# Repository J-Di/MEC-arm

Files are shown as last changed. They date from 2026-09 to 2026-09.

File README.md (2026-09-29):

<h1>MEC-Arm</h1>

MEC-Arm logo

## Overview
MEC-Arm is a six degree of freedom robotic arm which is currently being designed from scratch by 2 students team. The team is composed of a mechanical and electrical engineering student, working together to realize this shared personal project. The overall objective is to create a fully functional, precise, and practical arm, while creating many of the required components from scratch along the way. This repository contains both the mechanical and the electrical side of the project, after all, this is a **M**echanical **E**lectrical **C**ollaboration -Arm :)

Find all the Documentation here: [MEC-Arm Documentation Page](https://j-di.github.io/MEC-arm/)

### Key Features:

#### Arm
- Joint layout: waist (roll), shoulder (pitch), elbow (pitch), 3-axis wrist (roll, pitch, roll)
- Arm weight: TBD
- End effector: gripper, driven by the 7th motor
- Max joint speed: 90 RPM (shoulder)

#### Actuation

- Actuators: 7× brushless motors with custom cycloidal gearboxes
- Gear ratios: 19:1, 25:1, 15:1
- Motor control: FOC at every joint
- Position feedback: on-board magnetic encoders

#### Power & control

- Battery: 6S LiPo, 25.2–18V, TBD mA
- Communication: CAN bus 
- Host: controlled from a raspberry pi

## Timeline

```mermaid
flowchart LR
    subgraph Shared
        A[Requirements defined]
        B[Arm structure decided]
        C[Joint torque calculations]
        D[Motors sourced]
    end

    subgraph Electrical
        E[ESC design]
        H[ESC bring-up and testing]
        P[Power distribution and coordination board]
    end

    subgraph Mechanical
        F[Preliminary arm structure]
        G[Gearbox design]
        I[Joint assembly]
    end

    K[Per-joint gearbox testing]
    L[Torque characterization]
    J[Full arm integration]
    S[Software begins]

    A --> B --> C --> D
    D --> E --> H
    D --> P
    D --> F --> G --> I
    H --> K
    G --> K
    K --> L
    L --> J
    I --> J
    P --> J
    J --> S

    classDef done fill:#2da44e,stroke:#1a7f37,color:#fff
    classDef wip  fill:#d4a72c,stroke:#9a6700,color:#fff
    classDef todo fill:#8c959f,stroke:#57606a,color:#fff
    class A,B,C,D,F done
    class E,G,P wip
    class H,I,J,K,L,S todo
```

🟩 Done · 🟨 In progress · ⬜ Planned

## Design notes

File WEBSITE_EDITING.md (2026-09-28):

# Editing the MEC-Arm website

The website is plain HTML, CSS, and JavaScript in the repository's `docs/` folder. GitHub Pages publishes that folder from `main`. There is no npm install, generator, or build command.

## Where things live

| File or folder | Edit it to change… |
| --- | --- |
| `docs/index.html` | The homepage text, project goals, image gallery, timeline lists, and documentation cards. |
| `docs/styles.css` | Colors, spacing, type, cards, sidebar, and mobile layout. Sitewide color variables are at the top. |
| `docs/electrical/` | Electrical landing page, hardware boards and subsystems, and firmware pages. |
| `docs/mechanical/` | Structure, gearbox, joint, and gripper pages. |
| `docs/software/` | Host, motion, and testing-tool pages. |
| `docs/docs.js` | Shared header, sidebar, breadcrumbs, and the list of project pages (`sitePages`). |
| `docs/gallery.js` | Previous, next, and slide selection for the homepage gallery. |
| `docs/assets/gallery-placeholder.svg` | Temporary image shown until you add project photos. |
| `docs/assets/MEC_Logo.svg` | The supplied logo used in the header, footer, homepage, and favicon. |

Each documentation topic is a real `.html` file. For example, the ESC sensing page is `docs/electrical/hardware/esc/feedback.html`. A folder's landing page is its `index.html`, such as `docs/electrical/hardware/esc/index.html`.

## Update existing text

Open the page's `.html` file in an editor. Its `<h1>` is the page title. Paragraphs and lists in `<main class="docs-content">` are the visible content. The current descriptions are starting points; replace them with your design notes, images, tables, and measured results as the project develops. Keep planned values distinct from measured results.

On the homepage, edit the introductory paragraphs, the three lists in `<section class="status-band">`, and the three cards in `<section class="documentation">`. To update a milestone, move its `<li>…</li>` to the appropriate list. The small status label on an individual topic page is inside `<span class="status-pill">…</span>`.

The homepage's GitHub link is directly in `docs/index.html`. The GitHub link on documentation pages is set by `repoUrl` near the bottom of `docs/docs.js`.

To add an image, place it in `docs/assets/` and use a relative path from the page. From `docs/index.html` that looks like `<img src="assets/photo.jpg" alt="A description">`. From `docs/electrical/index.html`, use `../assets/photo.jpg`.

### Replace homepage gallery images

The four `<figure class="gallery-slide">` blocks in `docs/index.html` are the arm, ESC board, gearbox, and assembly slides. Place your photos in `docs/assets/`, then change each slide's `<img src="assets/gallery-placeholder.svg">` to its photo path (for example, `src="assets/arm.jpg"`). Update the image's `alt` text and the `<figcaption>` as well. The placeholder is reused for now; it is not a drawing of the actual arm. The previous/next arrows and four dots work without any changes to `gallery.js`.

### Add the S-Curve algorithm diagram

The page is `docs/electrical/firmware/s-curve.html`. Keep your editable `.drawio` file in `docs/assets/trajectory/` and export a separate SVG into the same folder for the website. SVG keeps text and lines sharp when readers zoom into a large diagram. Replace the "Detailed draw.io diagram coming soon" block on that page with:

```html
<figure class="doc-figure">
  <a href="../../assets/trajectory/s-curve-algorithm.svg" target="_blank" rel="noopener noreferrer">
    <img src="../../assets/trajectory/s-curve-algorithm.svg" alt="Diagram of the S-Curve trajectory planner" loading="lazy">
  </a>
  <figcaption><a href="../../assets/trajectory/s-curve-algorithm.svg" target="_blank" rel="noopener noreferrer">Open the full-size algorithm diagram ↗</a></figcaption>
</figure>
```

The inline preview gives context while the full-size link lets readers zoom and pan through the details. If the exported SVG is very large, a PNG preview with the SVG as the full-size link also works.

## Add a new topic page

Example: add a PWM page under the ESC.

1. Copy `docs/electrical/hardware/esc/feedback.html` to `docs/electrical/hardware/esc/pwm.html`.
2. Edit its `<title>`, `<h1>`, description, status, and main content. Give its `<body>` a unique `data-page="esc-pwm"`. Keep `data-root="../../../"` because it is three folders below `docs/`.
3. Add this entry to the `sitePages` array in `docs/docs.js` next to the other ESC pages:

   ```js
   { id: "esc-pwm", label: "PWM", path: "electrical/hardware/esc/pwm.html", parent: "esc" },
   ```

4. Add a card linking to it in `docs/electrical/hardware/esc/index.html`, following one of the existing `<a class="topic-card">` examples.

The sidebar and breadcrumbs are built from `sitePages`. Use a unique `id`, make `parent` the ID of its containing topic, and make `path` relative to `docs/`. For a page at another depth, `data-root` needs one `../` for each folder between the page and `docs/`.

## Preview and publish

You can open `docs/index.html` in a browser for a quick local preview. All page links are relative.

After editing, run from the repository root:

```bash
git add docs WEBSITE_EDITING.md
git commit -m "Update project website"
git push
```

Check **Settings → Pages** if the site does not update. It should publish from `main` and `/docs`. Browser caches may take a few minutes to refresh; `Ctrl+Shift+R` reloads the current version.

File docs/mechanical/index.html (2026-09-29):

Skip to content

MEC-ARM / PROJECT DOCUMENTATION

Design in progress

# Mechanical

The six axis structure, seven actuators, and custom gearboxes turn the electrical system into a practical arm.

## Explore this area

↗Arm structureSix axis layout and CAD↗Cycloidal gearboxesCustom reductions and testing↗Joint assembliesPer-joint integration↗GripperMotor-driven end effector

## Layout

The joint sequence is waist roll, shoulder pitch, elbow pitch, and a roll–pitch–roll wrist. A seventh motor is planned for the gripper.

## Design and verification

The preliminary structure and joint torque calculations are listed as complete. Gearbox design is in progress; joint assembly and torque characterization are future milestones.

This project is ongoing. Design goals, planned work, and measured results will be distinguished as the pages grow.

## Continue exploring

← Project overview

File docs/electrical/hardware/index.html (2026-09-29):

Skip to content

MEC-ARM / PROJECT DOCUMENTATION

Design in progress

# Electrical hardware

Two board families form the planned electrical backbone: one controller behind each motor and one central power and coordination board.

## Explore this area

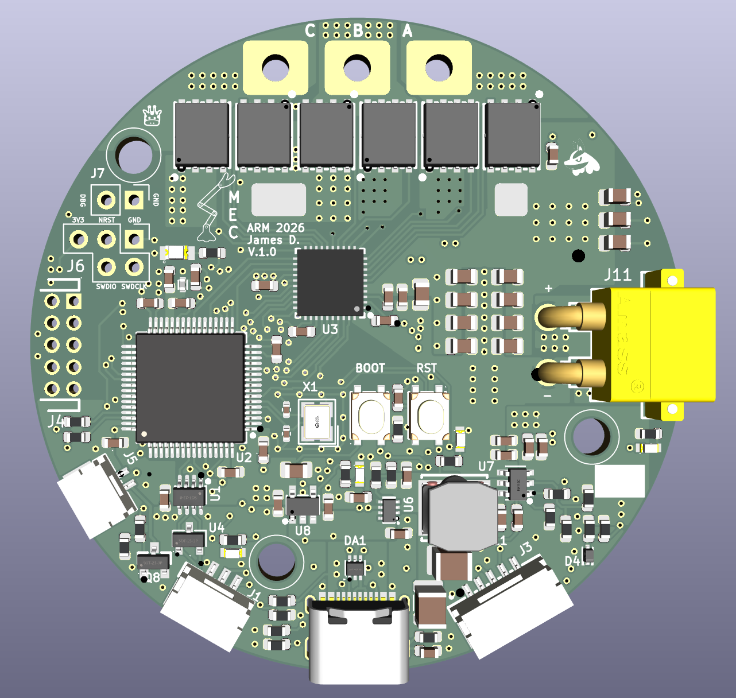
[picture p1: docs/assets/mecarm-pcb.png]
Joint ESC PCB
↗ Joint ESC  Compact controller at each motor ↗Power & coordination boardNot designed yetCentral power and connections

## Joint-level electronics

Each ESC is intended to fit behind a motor so it can read the motor-shaft magnetic encoder without a separate external encoder coupling. The same controller design is intended to serve different joints.

## Central electronics

The separate board is planned to distribute and convert power, coordinate connections, and provide a host-to-arm interface. Its final architecture remains under design.

This project is ongoing. Design goals, planned work, and measured results will be distinguished as the pages grow.

## Continue exploring

← ElectricalProject overview ↗

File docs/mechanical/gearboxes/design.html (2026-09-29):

Skip to content

MEC-ARM / PROJECT DOCUMENTATION

Design in progress

# Gearbox design

A dedicated record for cycloidal geometry, packaging, materials, and mechanical choices.

## Known direction

Custom cycloidal gearboxes are planned, with ratio targets of 19:1, 25:1, and 15:1. Final joint assignment and detailed geometry are still open.

## Design details to add

Record profiles, pin and bearing sizes, reduction calculations, tolerances, CAD revisions, and design tradeoffs here.

This project is ongoing. Design goals, planned work, and measured results will be distinguished as the pages grow.

## Continue exploring

← Cycloidal gearboxesProject overview ↗

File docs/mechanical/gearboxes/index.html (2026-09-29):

Skip to content

MEC-ARM / PROJECT DOCUMENTATION

Design in progress

# Cycloidal gearboxes

Custom gearboxes are planned for the brushless actuators to match motor speed to joint torque and motion.

## Explore this area

↗Gearbox designProfiles and packaging↗Gearbox testingTorque and backlash validation

## Current targets

The README lists ratio targets of 19:1, 25:1, and 15:1. Assignment of each ratio to a specific joint is not stated there, so this site does not assign them.

## Testing plan

Document the gearbox geometry, bearing and pin choices, tolerances, assembly, efficiency, backlash, and per-joint torque tests as they become available.

This project is ongoing. Design goals, planned work, and measured results will be distinguished as the pages grow.

## Continue exploring

← MechanicalProject overview ↗

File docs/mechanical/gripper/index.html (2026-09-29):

Skip to content

MEC-ARM / PROJECT DOCUMENTATION

Planned

# Gripper

The end effector is planned as a gripper driven by the seventh brushless motor.

## Current concept

The README identifies a motor-driven gripper but does not define finger geometry, transmission, force, or stroke yet.

## Future content

Add mechanism options, grasp targets, force estimates, CAD, and tests when the end-effector design begins.

This project is ongoing. Design goals, planned work, and measured results will be distinguished as the pages grow.

## Continue exploring

← MechanicalProject overview ↗

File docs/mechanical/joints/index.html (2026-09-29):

Skip to content

MEC-ARM / PROJECT DOCUMENTATION

Planned

# Joint assemblies

Each joint brings together a motor, gearbox, support structure, encoder, and compact ESC.

## Explore this area

↗Waist jointBase roll axis↗Shoulder & elbowLoad-bearing pitch axes↗Three-axis wristRoll–pitch–roll orientation

## Integration

The joint assembly milestone follows the preliminary arm structure and gearbox design. Per-joint gearbox testing and torque characterization are planned before full integration.

## Per-joint records

The pages below separate the waist, shoulder and elbow, and wrist. Each can grow to include ratio, limits, mass, CAD, and measured performance.

This project is ongoing. Design goals, planned work, and measured results will be distinguished as the pages grow.

## Continue exploring

← MechanicalProject overview ↗

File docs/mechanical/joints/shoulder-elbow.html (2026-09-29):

Skip to content

MEC-ARM / PROJECT DOCUMENTATION

Planned

# Shoulder & elbow

The two pitch axes position the arm and carry much of its working load.

## Role

Shoulder pitch and elbow pitch follow the waist roll axis. The README lists a 90 RPM maximum joint-speed target for the shoulder.

## To document

Add each joint's torque requirement, gearbox, structural support, range, CAD, and tests as the assemblies mature.

This project is ongoing. Design goals, planned work, and measured results will be distinguished as the pages grow.

## Continue exploring

← Joint assembliesProject overview ↗

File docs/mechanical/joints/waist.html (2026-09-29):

Skip to content

MEC-ARM / PROJECT DOCUMENTATION

Planned

# Waist joint

The base roll axis supports and rotates the rest of the arm.

## Role

The waist is the first rotational axis in the six degree of freedom layout.

## To document

Add bearing support, gearbox ratio, motor selection, range, wiring path, CAD, and load cases when the joint design is ready.

This project is ongoing. Design goals, planned work, and measured results will be distinguished as the pages grow.

## Continue exploring

← Joint assembliesProject overview ↗

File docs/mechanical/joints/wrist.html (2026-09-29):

Skip to content

MEC-ARM / PROJECT DOCUMENTATION

Planned

# Three-axis wrist

The roll–pitch–roll wrist orients the end effector at the end of the arm.

## Layout

Three rotational axes at the wrist complete the six degree of freedom joint sequence.

## To document

Add packaging, motor and gearbox choices, axis intersections, encoder access, cable routing, and validation once defined.

This project is ongoing. Design goals, planned work, and measured results will be distinguished as the pages grow.

## Continue exploring

← Joint assembliesProject overview ↗

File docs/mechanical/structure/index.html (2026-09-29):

Skip to content

MEC-ARM / PROJECT DOCUMENTATION

Preliminary design completed

# Arm structure

The arm layout organizes six degrees of freedom from the waist through the wrist.

## Joint sequence

Waist roll → shoulder pitch → elbow pitch → wrist roll → wrist pitch → wrist roll. The current plan adds a separate motor-driven gripper.

## Next documentation

Add CAD renders, dimensions, mass estimates, materials, joint range limits, and assembly drawings as the design is finalized. The arm's final weight is still TBD.

This project is ongoing. Design goals, planned work, and measured results will be distinguished as the pages grow.

## Continue exploring

← MechanicalProject overview ↗

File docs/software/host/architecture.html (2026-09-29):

Skip to content

MEC-ARM / PROJECT DOCUMENTATION

Planned

# Host architecture

The host's processes, interfaces, and command flow will be documented here.

## Current boundary

The Raspberry Pi is the planned host, while motor control is assigned to the distributed joint ESCs.

## To define

Add process boundaries, configuration, state handling, network transport, startup order, and telemetry storage after the software architecture is chosen.

This project is ongoing. Design goals, planned work, and measured results will be distinguished as the pages grow.

## Continue exploring

← Raspberry Pi hostProject overview ↗

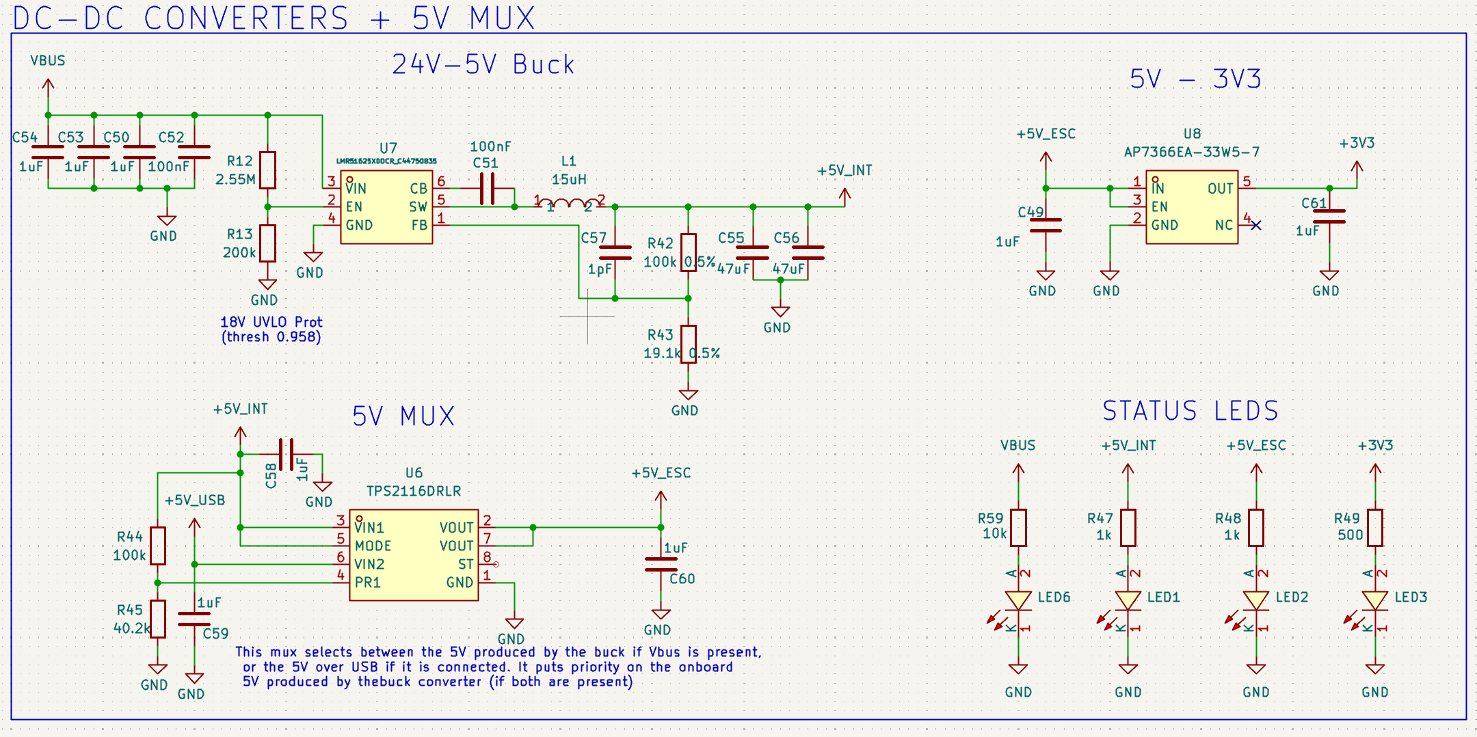
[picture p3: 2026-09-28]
docs/assets/esc/mec-converters-sch.png

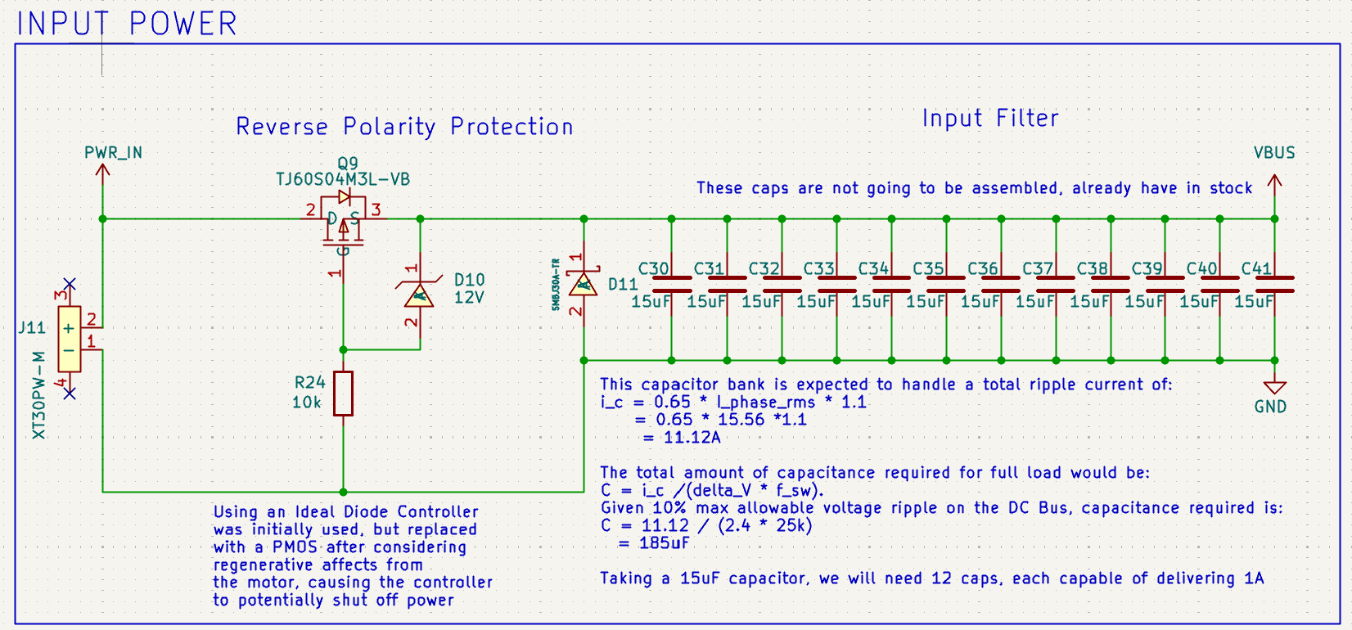
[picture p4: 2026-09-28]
docs/assets/esc/mec-pwr-filters-sch.png

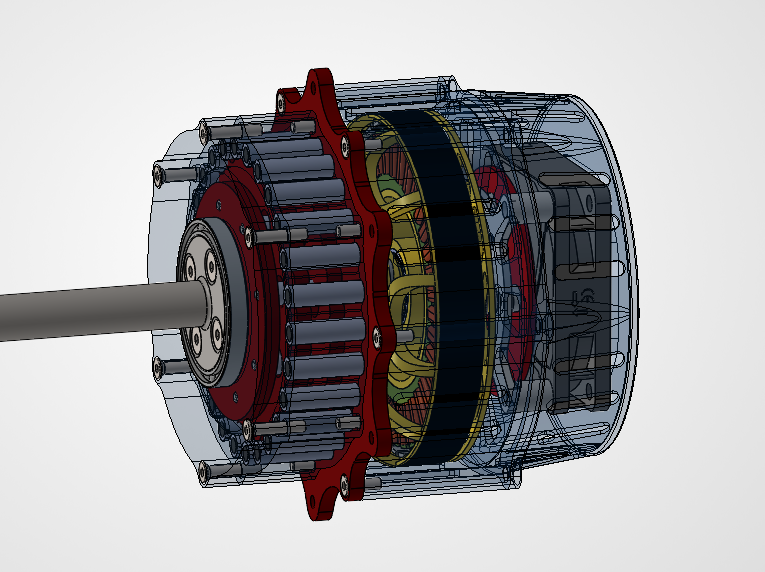
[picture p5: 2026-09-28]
docs/assets/mecarm-gearbox-prelim.png

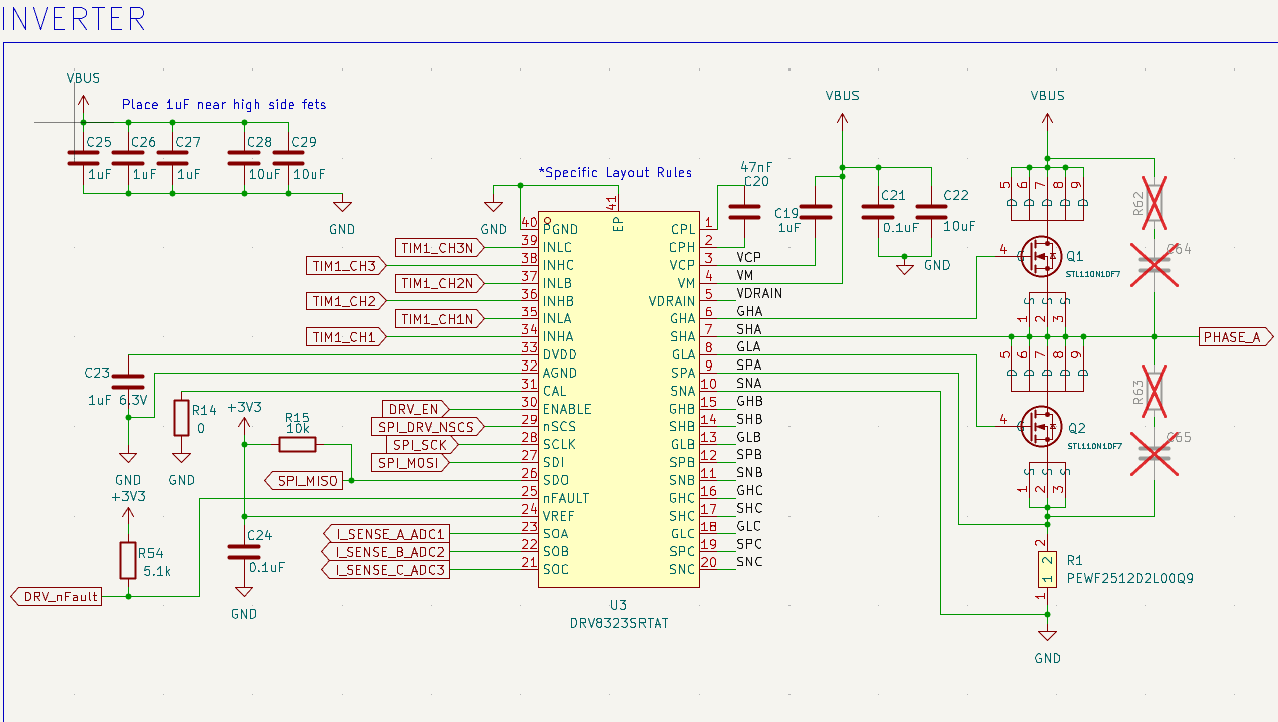
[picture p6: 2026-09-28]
docs/assets/esc/mec-inverter-sch.png

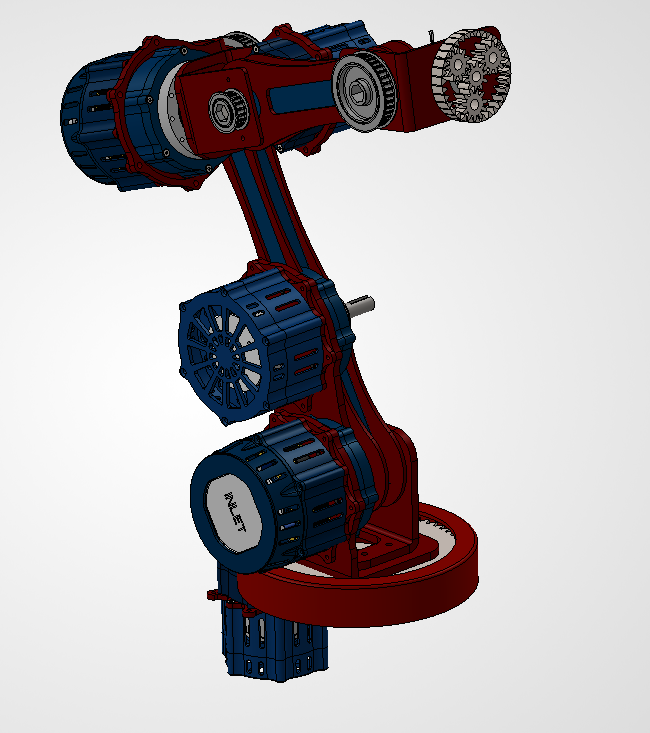
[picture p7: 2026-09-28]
docs/assets/mecarm-prelim.png

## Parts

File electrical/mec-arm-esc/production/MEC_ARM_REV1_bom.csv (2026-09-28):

Designator | Footprint | Quantity | Value | LCSC Part #
C10, C11, C16, C44, C45, C7, C8, C9 | C_0603 | 8 | 100nf | C108079
C12 | C_0805 | 1 | 10uf | C711098
C13, C43 | C_0603 | 2 | 10nf | C519406
C14, C15, C49, C58, C59, C60, C61 | C_0603 | 7 | 1uf | C106248
C17, C18 | 0402 | 2 | 16pF | C5142569
C19 | C_0603 | 1 | 1uF | C14664
C20 | C_0603 | 1 | 47nF | C513577
C21 | C_0603 | 1 | 0.1uF | C14663
C22, C28, C29 | C_0805 | 3 | 10uF | C162422
C23 | C_0603 | 1 | 1uF 6.3V | C2169508
C24, C42, C62 | C_0603 | 3 | 0.1uF | C108079
C25, C26, C27, C50, C53, C54 | C_0603 | 6 | 1uF | C559769
C30, C31, C32, C33, C34, C35, C36, C37, C38, C39, C40, C41 | C_0805 | 12 | 15uF | C162422
C46, C47, C48 | C_0603 | 3 | 10pF | C2168592
C51, C52 | C_0603 | 2 | 100nF | C14663
C55, C56 | 1210 | 2 | 47uF | C77101
C57 | C_0603 | 1 | 1pF | C29936
D1, D2, D3, D4, D5 | SOD-523_L1.2-W0.8-LS1.6-RD-1 | 5 | BAT30KFILM | C2926449
D10 | SOD-123F_L2.8-W1.8-LS3.7-RD | 1 | 12V | C177013
D11 | SMB_L4.6-W3.6-LS5.3-RD | 1 | SMBJ30A-TR | C133663
DA1, DA2 | SOT-666-6_L1.6-W1.2-P0.50-LS1.6-BR | 2 | USBLC6-2P6 | C15999
FB1 | L0402 | 1 | BLM15BX601SN1D | C710336
J1 | CONN-SMD_GT-A1257WRS-103SBT01 | 1 | GT-A1257WRS-103SBT01 | C22472755
J10 | PHASE_PAD | 1 | ~
J11 | CONN-TH_XT30PW-M | 1 | XT30PW-M | C431092
J12 | 3x3BusBar Pad | 1 | ~
J3 | CONN-SMD_5P-P1.25_SM05B-GHS-TB-LF-SN | 1 | SM05B-GHS-TB | C189896
J5 | CONN-SMD_SM02B-GHS-TB-LF-SN | 1 | XY-SM02B-GHS-TB | C54582897
J8 | TestPadArray1x4 | 1 | ~
J9 | 5x3BusBar Pad | 1 | ~
L1 | IND-SMD_L6.0-W6.0_VLS6045EX | 1 | 15uH | C404502
LED1, LED2, LED3, LED6 | LED0603-RD_RED | 4 | 150060RS75000 | C3030991
LED5 | LED0805-RD | 1 | LTST-C171KGKT | C98224
Q1, Q2, Q3, Q4, Q5, Q6 | DFN-8_L5.8-W4.9-P1.27-LS6.0-BL-1 | 6 | STL110N10F7 | C672185
Q8 | SOT-23_L2.9-W1.3-P1.90-LS2.4-BR | 1 | PJA138K_R1_00001 | C2902548
Q9 | TO-252-2_L6.6-W6.1-P4.58-LS9.9-TL | 1 | TJ60S04M3L-VB | C7494452
R1, R2, R3 | RES-SMD_L6.3-W3.2_R2512 | 3 | PEWF2512D2L00Q9 | C19697176
R11, R15, R24, R59 | R_0603 | 4 | 10k | C98220
R12, R23 | R_0603 | 2 | 2.55M | C54102347
R13 | R_0603 | 1 | 200k | C2907009
R14 | R_0603 | 1 | 0 | C2906974
R16, R17 | R_0603 | 2 | 10 | C844919
R18, R19, R54 | R_0603 | 3 | 5.1k | C2907044
R20, R21, R33, R44 | R_0603 | 4 | 100k | C2906980
R22 | R_0603 | 1 | 120 | C2906988
R27, R28, R29, R30, R31, R32, R70, R71 | R_0603 | 8 | 1.8k | C286575
R34 | R_0603 | 1 | 6.34k | C321969
R35 | R_0603 | 1 | 3.24k | C728589
R36, R37, R38, R39, R40, R41, R46, R47, R48, R50, R51, R52, R53, R55, R56, R57, R58, R60, R61, R68, R69 | R_0603 | 21 | 1k | C14676
R4 | R0603 | 1 | 10k | C153011
R42 | R_0603 | 1 | 100k 0.5% | C122538
R43 | R_0603 | 1 | 19.1k 0.5% | C861184
R45 | R_0603 | 1 | 40.2k | C286588
R49 | R_0603 | 1 | 500 | C73811
SW1, SW2 | SW-SMD_4P-L4.2-W3.4-P2.15-LS5.2 | 2 | SH-1808SN-250GF | C52092028
U1 | SOT-23-8_L2.9-W1.6-P0.65-LS2.8-BR | 1 | TCAN330DCNT | C2671056
U2 | LQFP-64_L10.0-W10.0-P0.50-LS12.0-BL | 1 | STM32G474RET3 | C1236669
U3 | WQFN-40_L6.0-W6.0-P0.50-TL-EP4.5 | 1 | DRV8323SRTAT | C2150452
U4 | SOT-23-3_L2.9-W1.3-P1.90-LS2.4-BR | 1 | ESD2CAN24DBZRQ1 | C5736151
U5 | TSSOP-14_L5.0-W4.4-P0.65-LS6.4-BL | 1 | AS5047P-ATSM_C22459881 | C22459881
U6 | SOT-583-8_L2.1-W1.6-P0.50-LS1.6-BL | 1 | TPS2116DRLR | C3235557
U7 | SOT-23-6_L2.9-W1.6-P0.95-LS2.9-BL | 1 | LMR51625XDDCR_C44750835 | C44750835
U8 | SOT-23-5_L3.0-W1.6-P0.95-LS2.8-BR | 1 | AP7366EA-33W5-7 | C22038443
USB1 | USB-C-SMD_GT-USB-7010B | 1 | USB4215-03-A | C37616412
X1 | CRYSTAL-SMD_4P-L3.2-W2.5-BL | 1 | 3225 8M 12PF 10PPM | C5181478

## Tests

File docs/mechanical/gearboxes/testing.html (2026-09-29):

Skip to content

MEC-ARM / PROJECT DOCUMENTATION

Planned

# Gearbox testing

Per-joint gearbox tests and torque characterization are milestones before full arm integration.

## Test goals

Verify assembled gearbox performance against the joint torque calculations and check for backlash, efficiency, heating, and wear.

## Results

Add fixtures, conditions, plots, and measured values here after physical testing. No test results are claimed yet.

This project is ongoing. Design goals, planned work, and measured results will be distinguished as the pages grow.

## Continue exploring

← Cycloidal gearboxesProject overview ↗

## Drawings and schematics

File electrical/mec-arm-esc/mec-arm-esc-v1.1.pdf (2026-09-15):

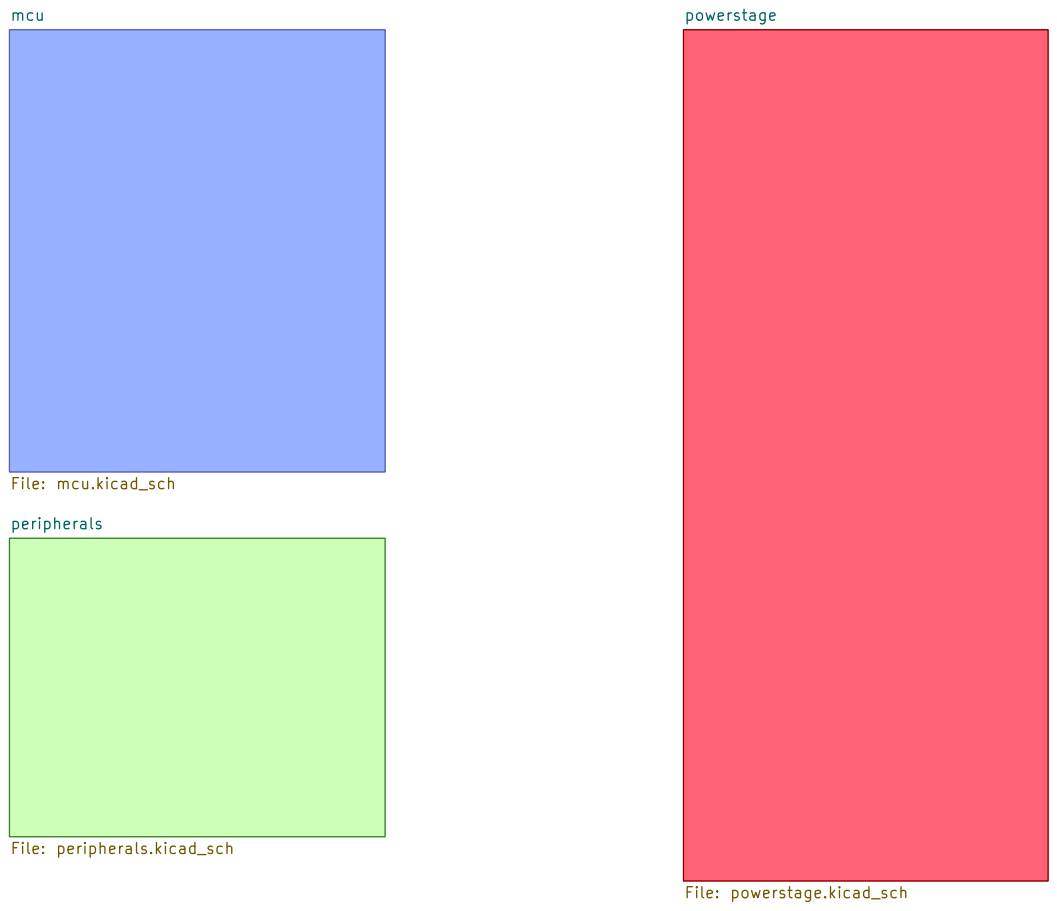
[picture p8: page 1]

peripherals File: peripherals.kicad_sch mcu

Sheet: /
File: mec-arm-esc.kicad_sch
Title: MEC-arm

Size: A4 | Rev: V1
KiCad E.D.A. 10.0.1 | Id: 1/4

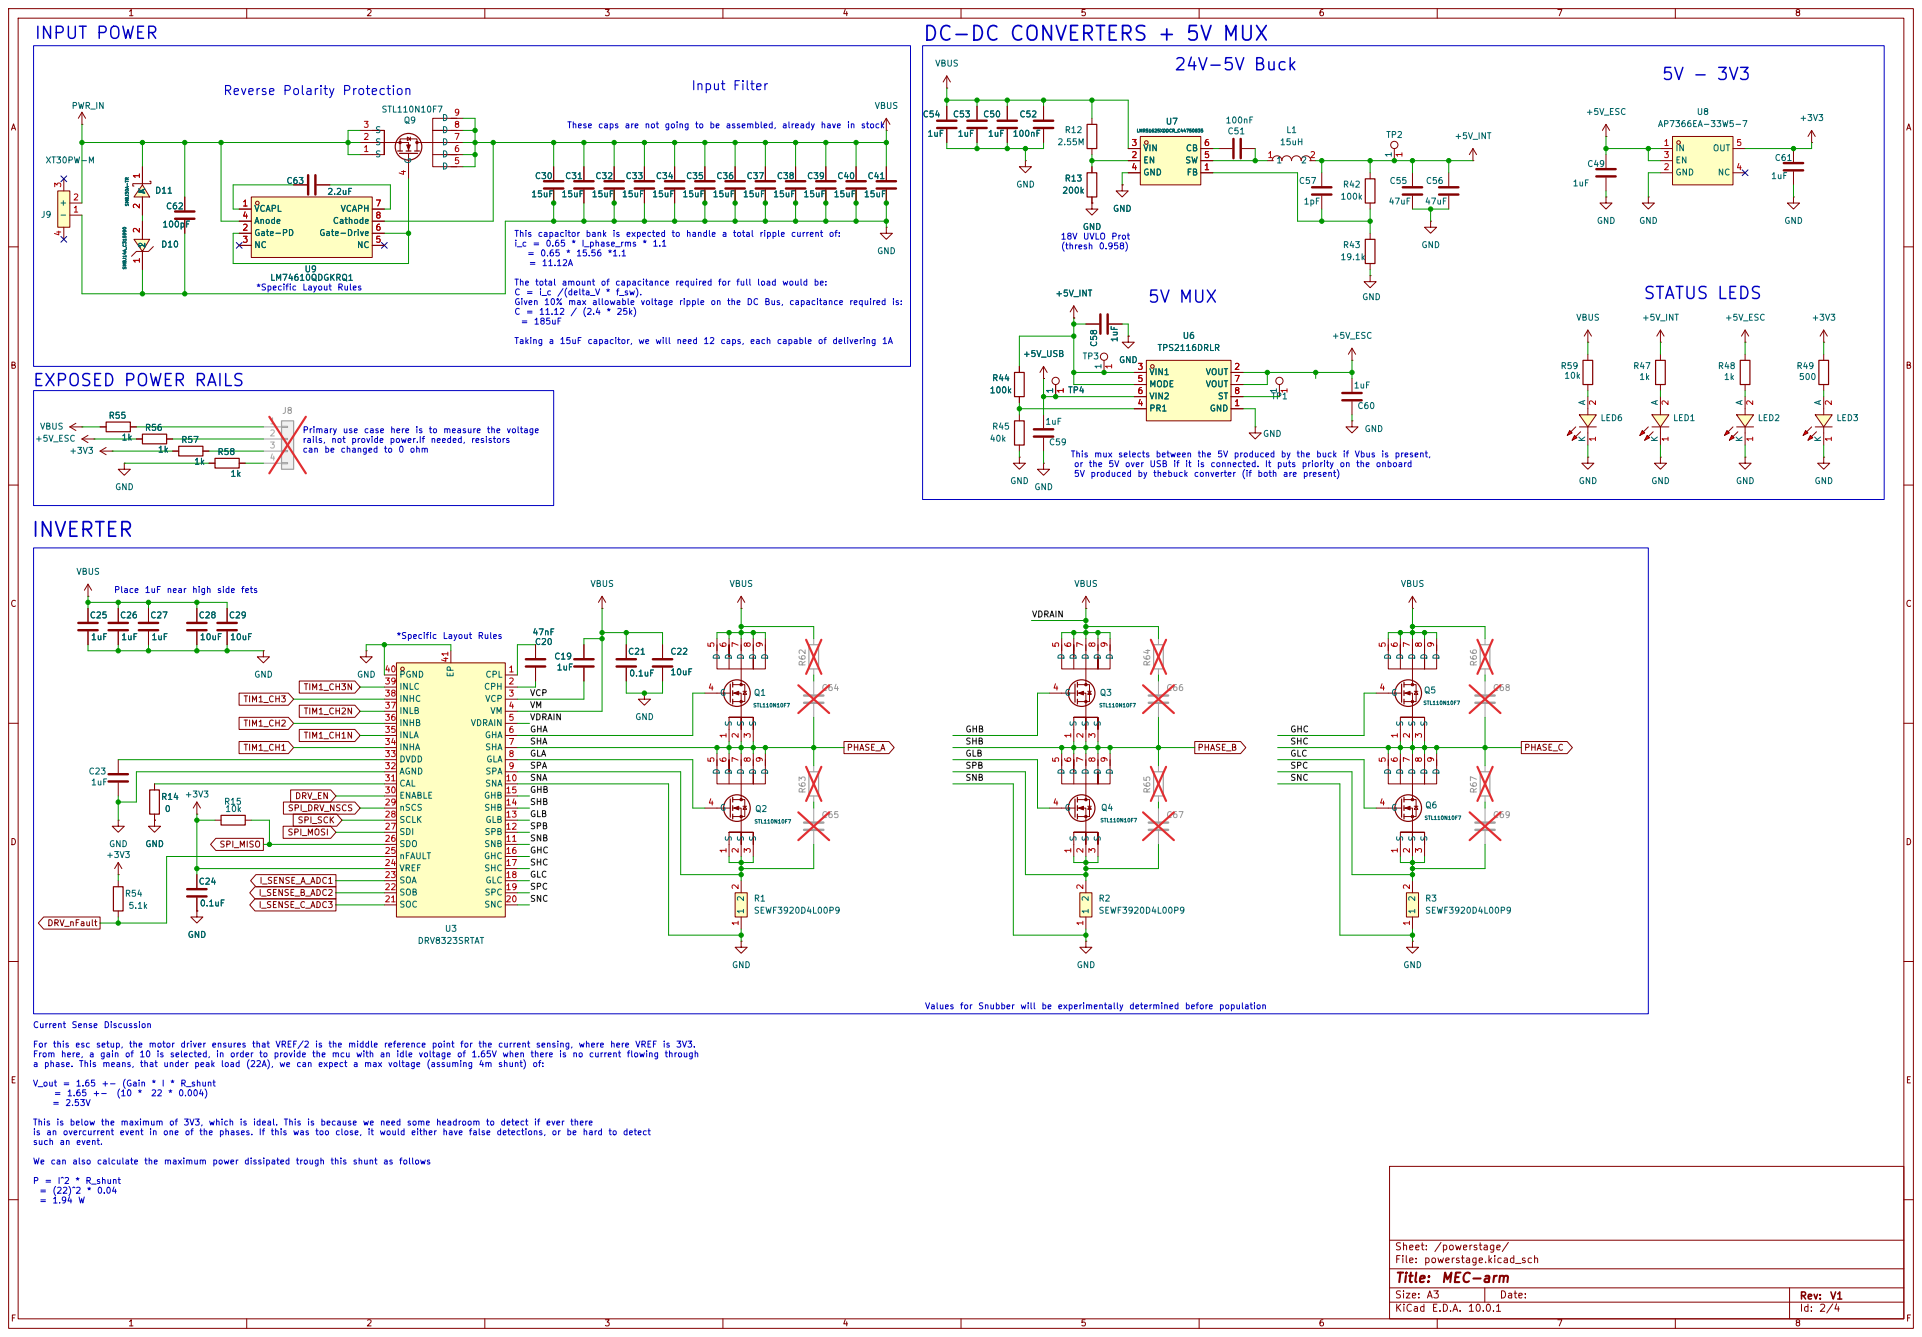
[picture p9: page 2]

These caps are not going to be assembled, already have in stock INPUT POWER

This capacitor bank is expected to handle a total ripple current of:
i_c = 0.65 * I_phase_rms * 1.1 = 0.65 * 15.56 *1.1 = 11.12A

This mux selects between the 5V produced by the buck if Vbus is present, or the 5V over USB if it is connected. It puts priority on the onboard 5V produced by thebuck converter (if both are present) 18V UVLO Prot (thresh 0.958)

The total amount of capacitance required for full load would be: C = i_c /(delta_V * f_sw). Given 10% max allowable voltage ripple on the DC Bus, capacitance required is: C = 11.12 / (2.4 * 25k) = 185uF

Taking a 15uF capacitor, we will need 12 caps, each capable of delivering 1A

*Specific Layout Rules Primary use case here is to measure the voltage
rails, not provide power.If needed, resistors can be changed to 0 ohm

SNB 11 SPB 12 GLB 13 SHB 14 GHB 15 GHC 16

This is below the maximum of 3V3, which is ideal. This is because we need some headroom to detect if ever there
is an overcurrent event in one of the phases. If this was too close, it would either have false detections, or be hard to detect such an event. We can also calculate the maximum power dissipated trough this shunt as follows P = I^2 * R_shunt = (22)^2 * 0.04 = 1.94 W

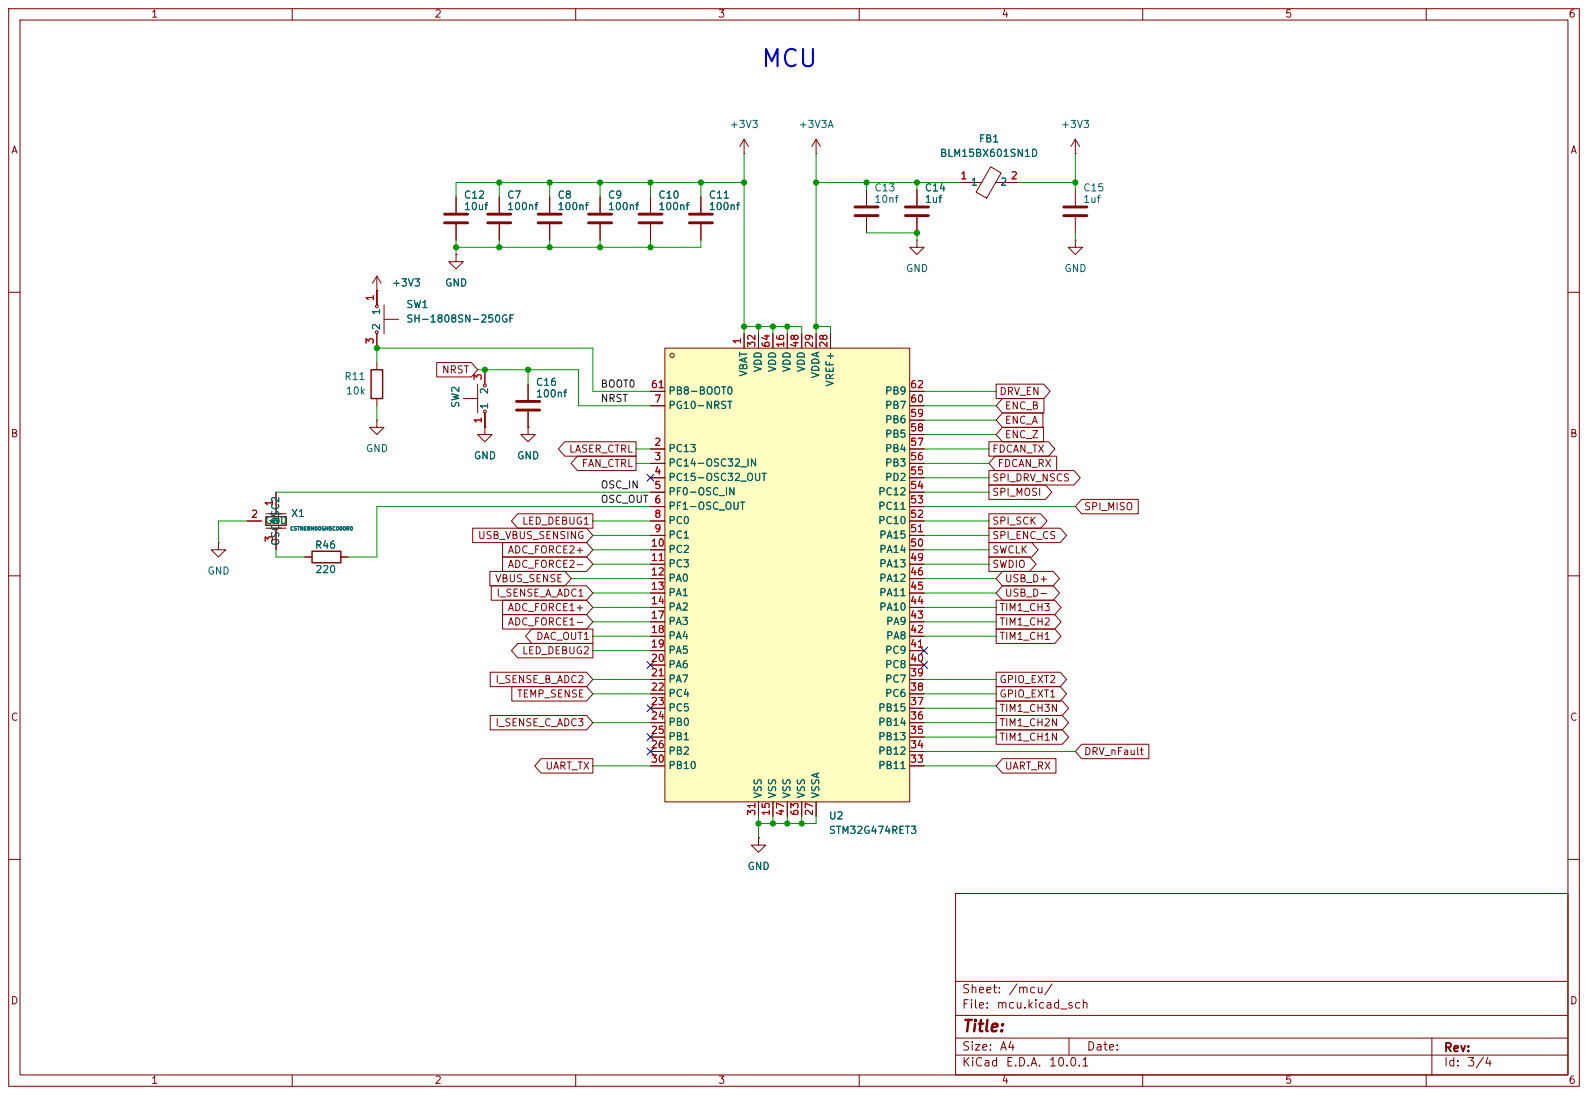
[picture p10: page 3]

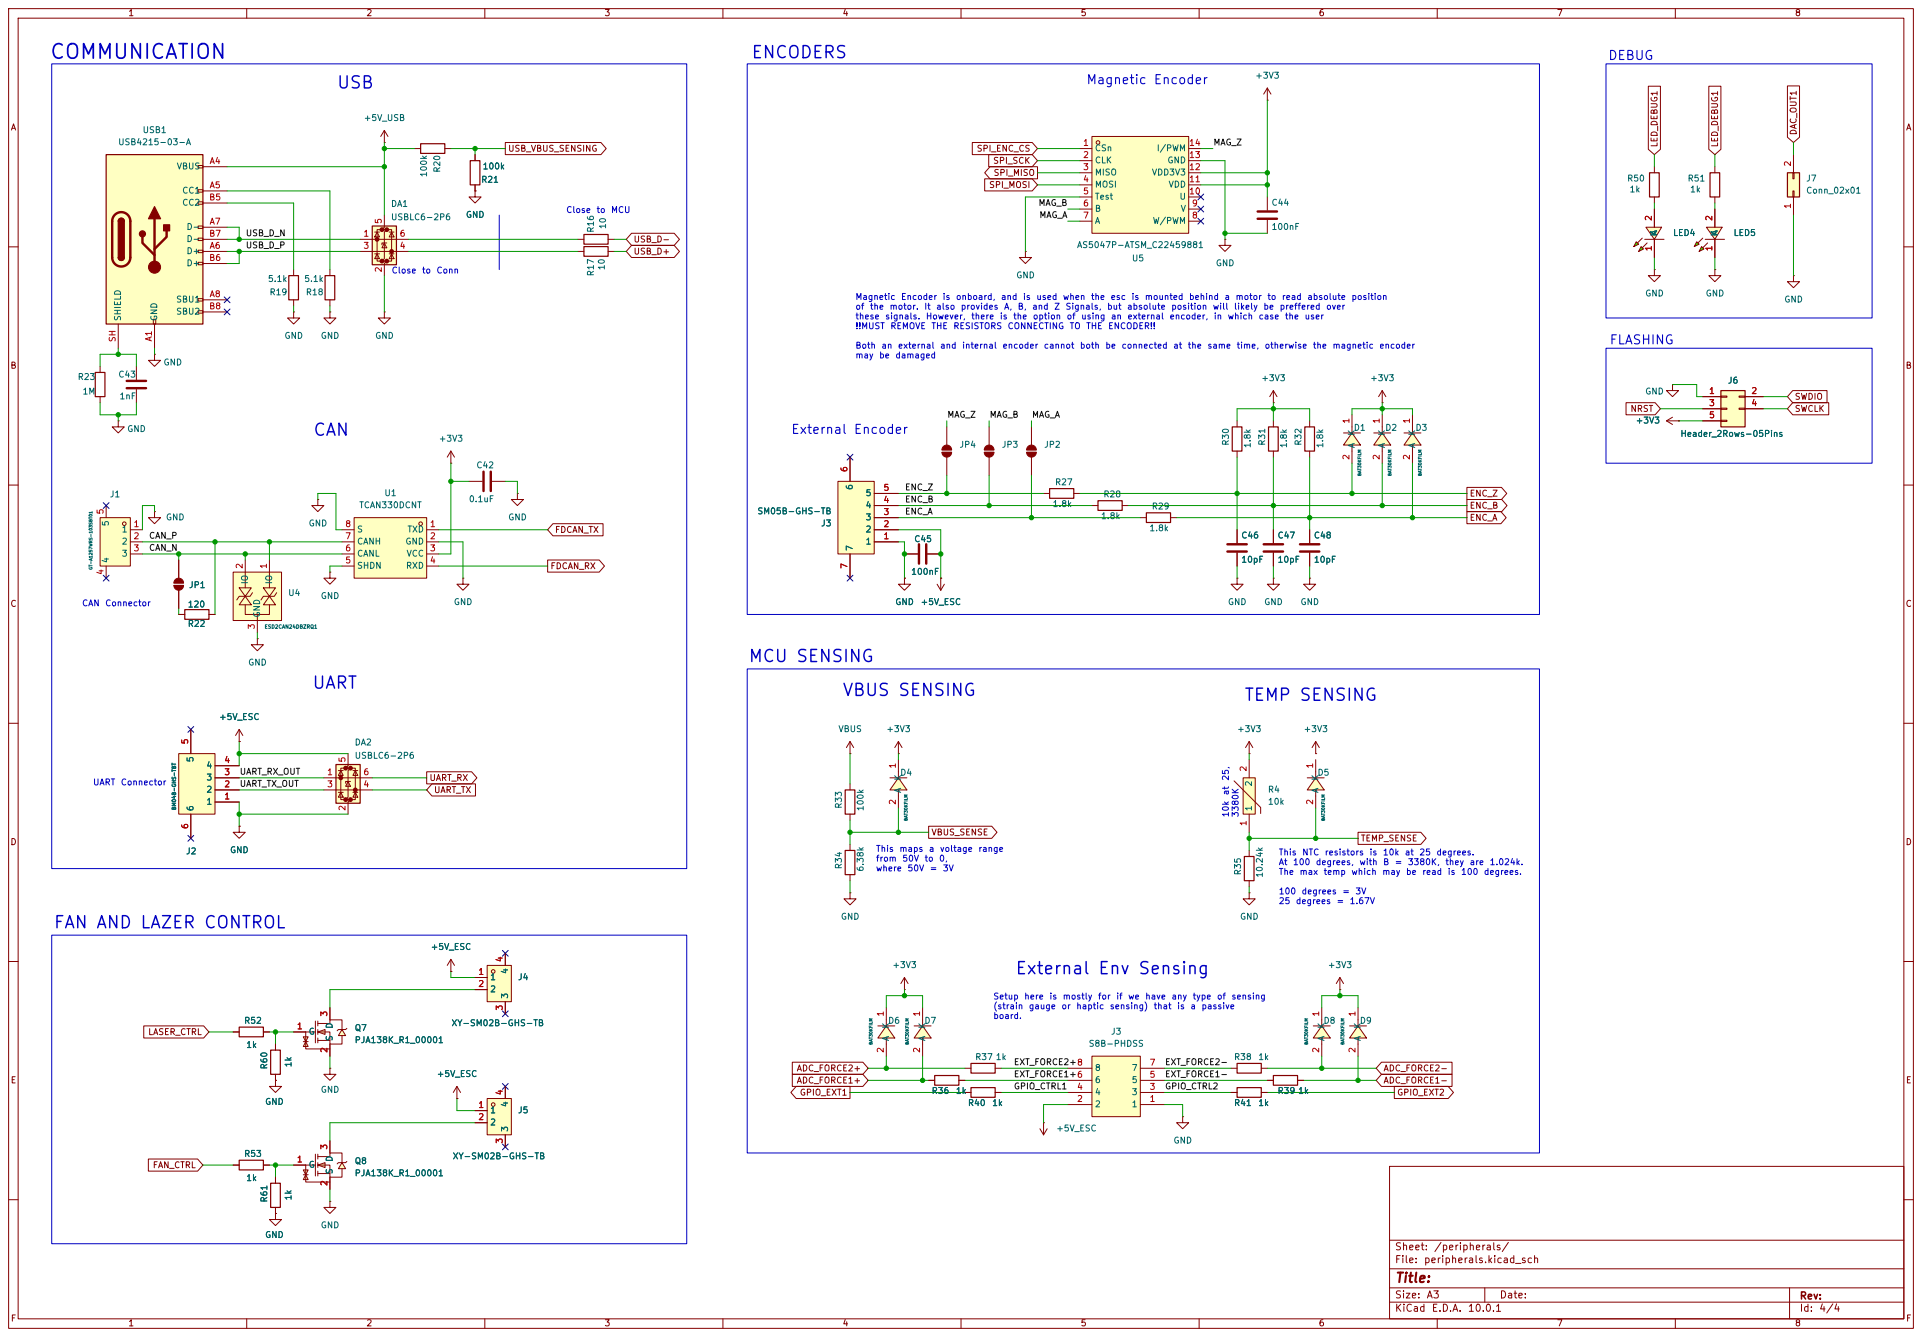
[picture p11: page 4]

3. (personal pref) Connector can be used for encoder pin debug 10k at 25, 3380K

XY-SM02B-GHS-TB GND A1
J1 GT-A1257WRS-103SBT01 R23

of the motor. It also provides A, B, and Z Signals, but absolute position will likely be preffered over
these signals. However, there is the option of using an external encoder, in which case the user
!!MUST REMOVE THE RESISTORS CONNECTING TO THE ENCODER!! Both an external and internal encoder cannot both be connected at the same time, otherwise the magnetic encoder may be damaged

(strain gauge or haptic sensing) that is a passive board. This maps a voltage range

This NTC resistors is 10k at 25 degrees. At 100 degrees, with B = 3380K, they are 1.024k.

The max temp which may be read is 100 degrees. 100 degrees = 3V 25 degrees = 1.67V

FAN AND LAZER CONTROL

Setup here is mostly for if we have any type of sensing

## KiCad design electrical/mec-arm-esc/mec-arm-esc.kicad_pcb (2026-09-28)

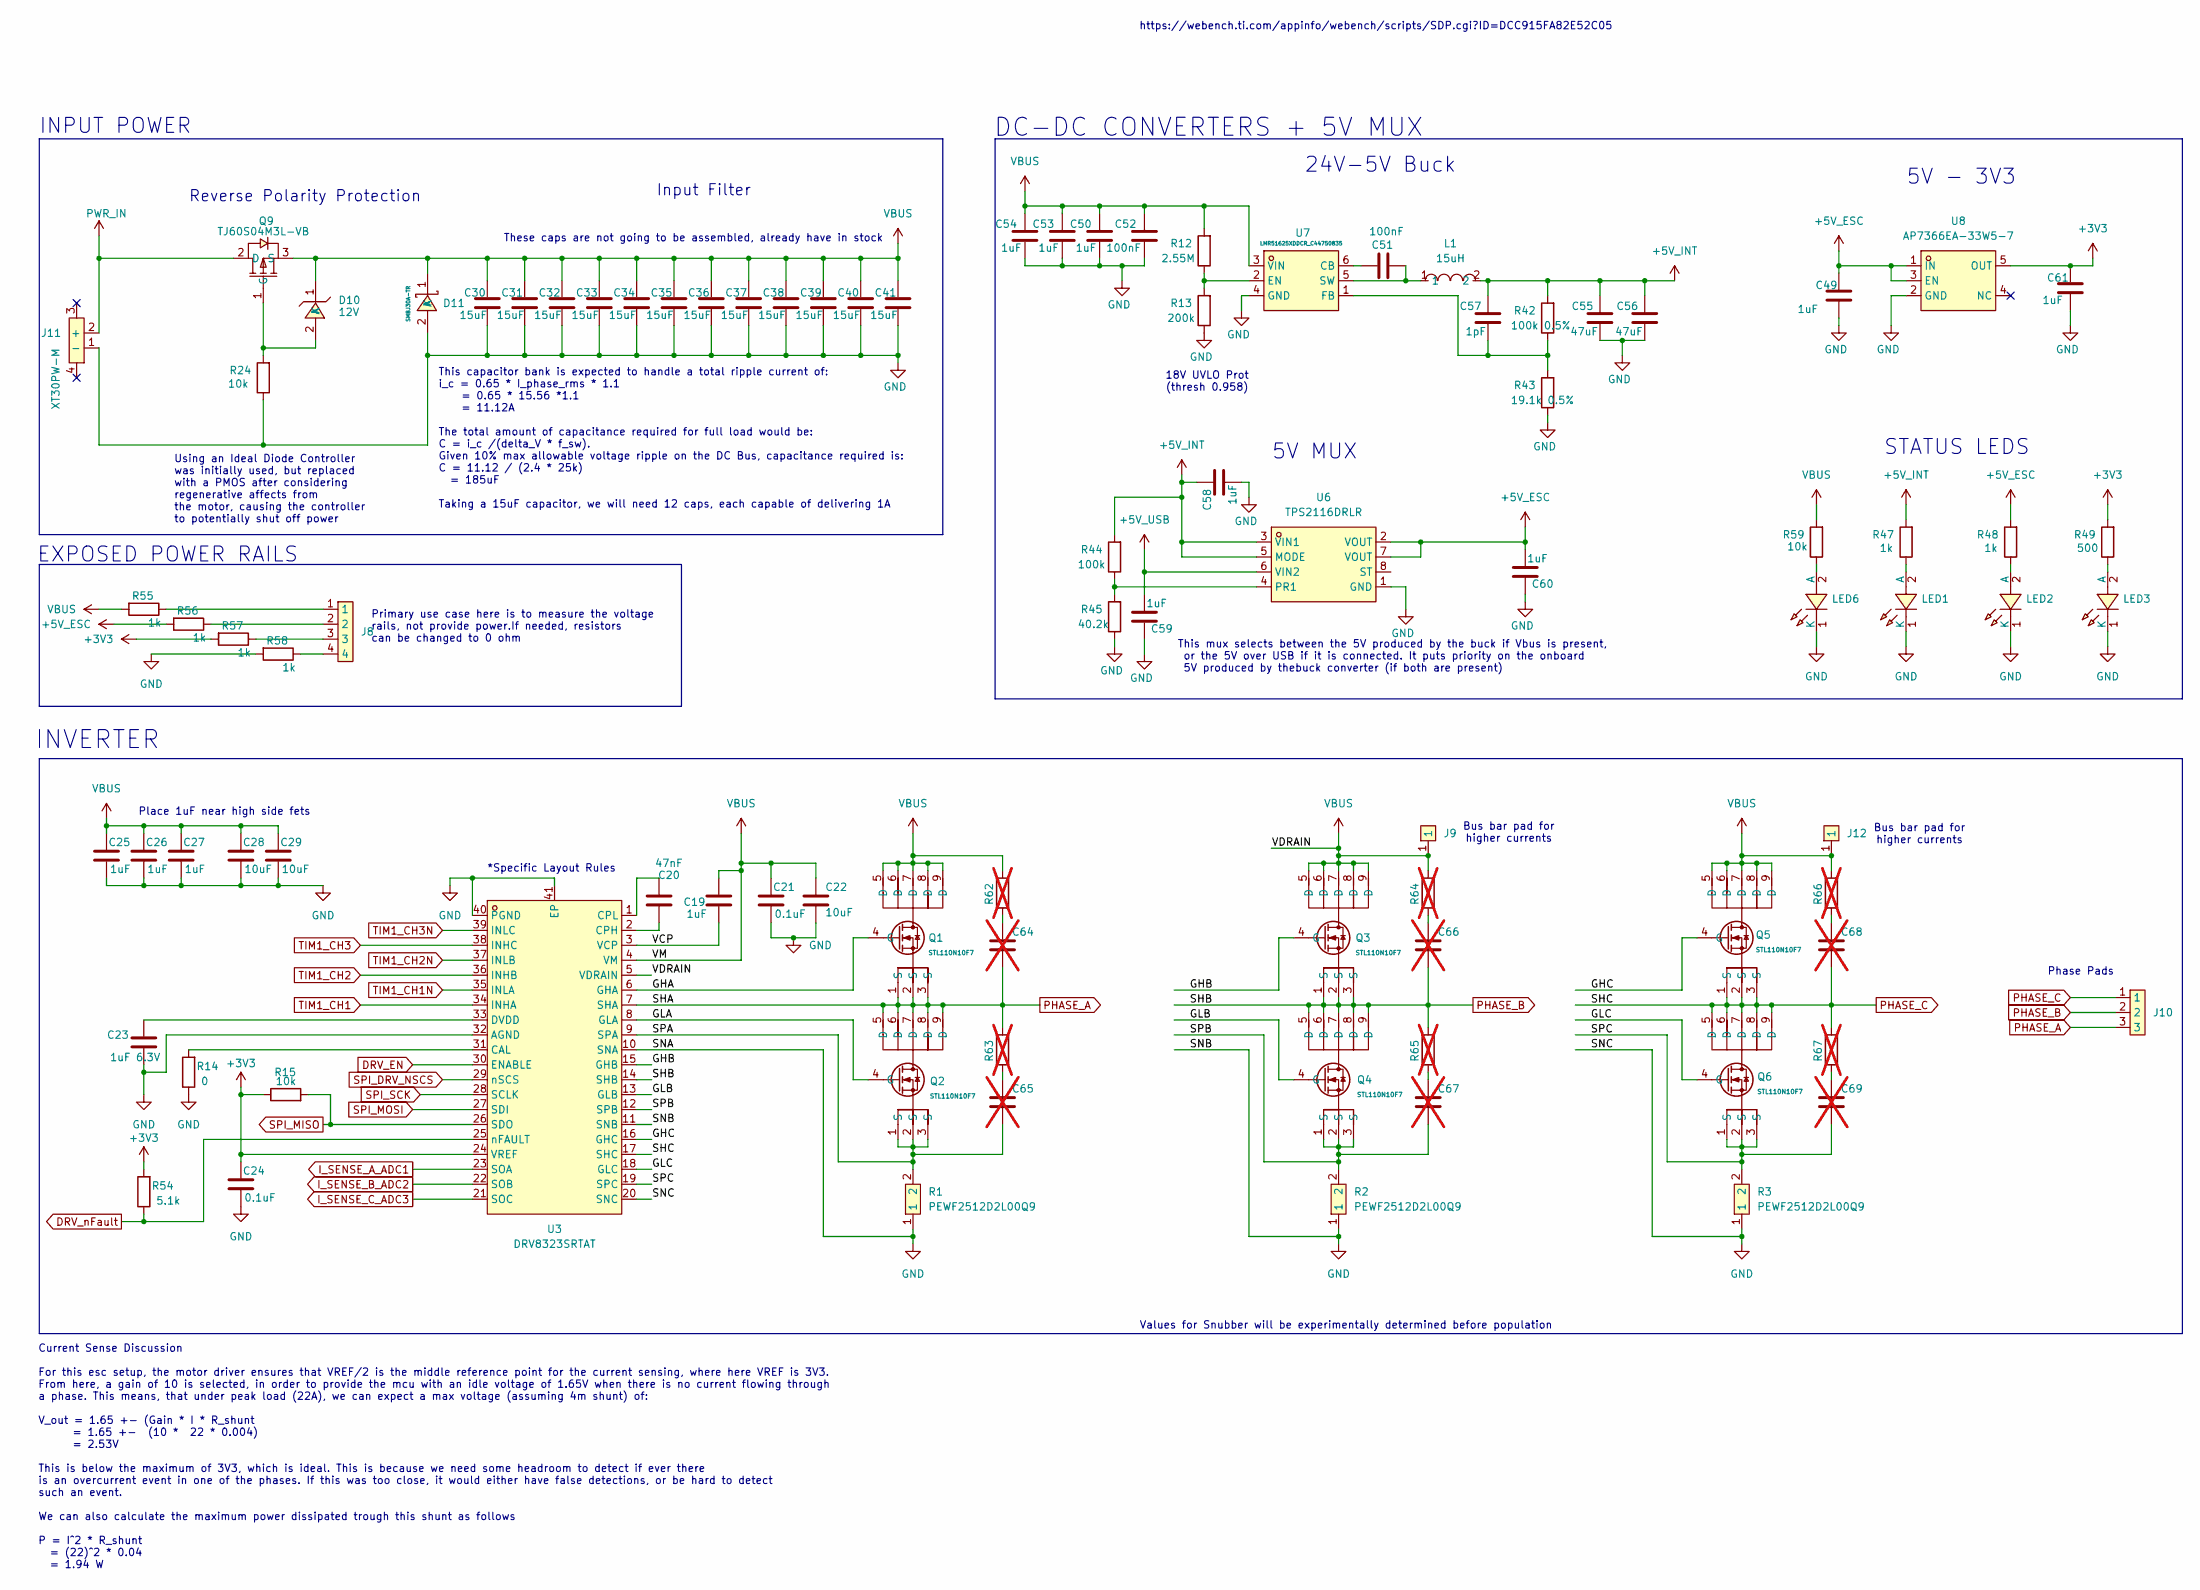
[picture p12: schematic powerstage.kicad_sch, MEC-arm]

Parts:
C19: 1uF; C_0603; LCSC Part C14664
C20: 47nF; C_0603; LCSC Part C513577
C21: 0.1uF; C_0603; LCSC Part C14663
C22, C28, C29: 10uF; C_0805; LCSC Part C162422
C23: 1uF 6.3V; C_0603; LCSC Part C2169508
C24: 0.1uF; C_0603; LCSC Part C108079
C25, C26, C27, C50, C53, C54: 1uF; C_0603; LCSC Part C559769
C30: 15uF; C_0805; LCSC Part# C162422
C31, C32, C33, C34, C35, C36, C37, C38, C39, C40, C41: 15uF; C_0805; LCSC Part C162422
C49, C58, C59, C60, C61: 1uF; C_0603; LCSC Part C106248
C51, C52: 100nF; C_0603; LCSC Part C14663
C55, C56: 47uF; C_1210_3225Metric; LCSC Part C77101
C57: 1pF; C_0603; LCSC Part C29936
C64, C65, C66, C67, C68, C69: 10uF; C_0603; not fitted
D10: 12V; SOD-123F_L2.8-W1.8-LS3.7-RD; MPN BZT52C12-13-F; LCSC Part C177013
D11: SMBJ30A-TR; SMB_L4.6-W3.6-LS5.3-RD; MPN SMBJ30A-TR; LCSC Part C133663
J8: TestPadArray1x4
J9: 5x3BusBar Pad
J10: PHASE_PAD
J11: XT30PW-M; CONN-TH_XT30PW-M; MPN XT30PW-M30.G.Y; LCSC Part C431092
J12: 3x3BusBar Pad
L1: 15uH; IND-SMD_L6.0-W6.0_VLS6045EX; MPN VLS6045EX-150M; LCSC Part C404502
LED1, LED2, LED3, LED6: 150060RS75000; LED0603-RD_RED; MPN 150060RS75000; LCSC Part C3030991
Q1, Q2, Q3, Q4, Q5, Q6: STL110N10F7; DFN-8_L5.8-W4.9-P1.27-LS6.0-BL-1; MPN STL110N10F7; LCSC Part C672185
Q9: TJ60S04M3L-VB; TO-252-2_L6.6-W6.1-P4.58-LS9.9-TL; MPN TJ60S04M3L-VB; LCSC Part C7494452
R1, R2, R3: PEWF2512D2L00Q9; RES-SMD_L6.3-W3.2_R2512; MPN PEWF2512D2L00Q9; LCSC Part C19697176
R12: 2.55M; R_0603; LCSC Part C54102347
R13: 200k; R_0603; LCSC Part C2907009
R14: 0; R_0603; LCSC Part C2906974
R15, R24, R59: 10k; R_0603; LCSC Part C98220
R42: 100k 0.5%; R_0603; LCSC Part C122538
R43: 19.1k 0.5%; R_0603; LCSC Part C861184
R44: 100k; R_0603; LCSC Part C2906980
R45: 40.2k; R_0603; LCSC Part C286588
R47, R48, R55, R56, R57, R58: 1k; R_0603; LCSC Part C14676
R49: 500; R_0603; LCSC Part C73811
R54: 5.1k; R_0603; LCSC Part C2907044
R62, R63, R64, R65, R66, R67: 1k; R_0603; not fitted
U3: DRV8323SRTAT; WQFN-40_L6.0-W6.0-P0.50-TL-EP4.5; MPN DRV8323SRTAT; LCSC Part C2150452
U6: TPS2116DRLR; SOT-583-8_L2.1-W1.6-P0.50-LS1.6-BL; MPN TPS2116DRLR; LCSC Part C3235557
U7: LMR51625XDDCR_C44750835; SOT-23-6_L2.9-W1.6-P0.95-LS2.9-BL; MPN LMR51625XDDCR; LCSC Part C44750835
U8: AP7366EA-33W5-7; SOT-23-5_L3.0-W1.6-P0.95-LS2.8-BR; MPN AP7366EA-33W5-7; LCSC Part C22038443

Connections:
+3V3: C24.1, C61.1, R15.1, R49.2, R54.2, R57.2, U3.24 (VREF), U8.5 (OUT); also elsewhere on the board
+5V_ESC: C49.1, C60.1, R48.2, R56.2, U6.2 (VOUT), U6.7 (VOUT), U8.1 (IN), U8.3 (EN); also elsewhere on the board
+5V_INT: C55.2, C56.2, C57.2, C58.2, L1.2, R42.2, R44.2, R47.2, U6.3 (VIN1), U6.5 (MODE)
+5V_USB: C59.1, U6.6 (VIN2); also elsewhere on the board
/powerstage/GHA: Q1.4 (G), U3.6 (GHA)
/powerstage/GHB: Q3.4 (G), U3.15 (GHB)
/powerstage/GHC: Q5.4 (G), U3.16 (GHC)
/powerstage/GLA: Q2.4 (G), U3.8 (GLA)
/powerstage/GLB: Q4.4 (G), U3.13 (GLB)
/powerstage/GLC: Q6.4 (G), U3.18 (GLC)
/powerstage/SPA: C65.2, Q2.1 (S), Q2.2 (S), Q2.3 (S), R1.2, U3.9 (SPA)
/powerstage/SPB: C67.2, Q4.1 (S), Q4.2 (S), Q4.3 (S), R2.2, U3.12 (SPB)
/powerstage/SPC: C69.2, Q6.1 (S), Q6.2 (S), Q6.3 (S), R3.2, U3.19 (SPC)
/powerstage/VCP: C19.2, U3.3 (VCP)
DRV_EN: U3.30 (ENABLE); also elsewhere on the board
DRV_nFault: R54.1, U3.25 (nFAULT); also elsewhere on the board
GND: C21.2, C22.2, C23.2, C24.2, C25.2, C26.2, C27.2, C28.2, C29.2, C30.2, C31.2, C32.2, C33.2, C34.2, C35.2, C36.2, C37.2, C38.2, C39.2, C40.2, C41.2, C49.2, C50.1, C52.1, C53.1, C54.1, C55.1, C56.1, C58.1, C59.2, C60.2, C61.2, D11.2 (A), J11.1 (-), LED1.1 (K), LED2.1 (K), LED3.1 (K), LED6.1 (K), R1.1, R2.1, R3.1, R13.1, R14.1, R24.1, R43.1, R45.1, R58.2, U3.10 (SNA), U3.11 (SNB), U3.20 (SNC), U3.32 (AGND), U3.40 (PGND), U3.41 (EP), U6.1 (GND), U7.4 (GND), U8.2 (GND); also elsewhere on the board
I_SENSE_A_ADC1: U3.23 (SOA); also elsewhere on the board
I_SENSE_B_ADC2: U3.22 (SOB); also elsewhere on the board
I_SENSE_C_ADC3: U3.21 (SOC); also elsewhere on the board
unnamed: C64.1, R62.2
unnamed: C65.1, R63.2
unnamed: C66.1, R64.2
unnamed: C67.1, R65.2
unnamed: C68.1, R66.2
unnamed: C69.1, R67.2
unnamed: D10.2 (A), Q9.1 (G), R24.2
unnamed: J8.1, R55.1
unnamed: J8.2, R56.1
unnamed: J8.3, R57.1
unnamed: J8.4, R58.1
unnamed: LED1.2 (A), R47.1
unnamed: LED2.2 (A), R48.1
unnamed: LED3.2 (A), R49.1
unnamed: LED6.2 (A), R59.1
unnamed: R14.2, U3.31 (CAL)
unnamed: C20.2, U3.2 (CPH)
unnamed: C20.1, U3.1 (CPL)
unnamed: C23.1, U3.33 (DVDD)
unnamed: R44.1, R45.2, U6.4 (PR1)
unnamed: C51.1, U7.6 (CB)
unnamed: R12.1, R13.2, U7.2 (EN)
unnamed: C57.1, R42.1, R43.2, U7.1 (FB)
unnamed: C51.2, L1.1, U7.5 (SW)
PHASE_A: C64.2, J10.3, Q1.1 (S), Q1.2 (S), Q1.3 (S), Q2.5 (D), Q2.6 (D), Q2.7 (D), Q2.8 (D), Q2.9 (D), R63.1, U3.7 (SHA)
PHASE_B: C66.2, J10.2, Q3.1 (S), Q3.2 (S), Q3.3 (S), Q4.5 (D), Q4.6 (D), Q4.7 (D), Q4.8 (D), Q4.9 (D), R65.1, U3.14 (SHB)
PHASE_C: C68.2, J10.1, Q5.1 (S), Q5.2 (S), Q5.3 (S), Q6.5 (D), Q6.6 (D), Q6.7 (D), Q6.8 (D), Q6.9 (D), R67.1, U3.17 (SHC)
PWR_IN: J11.2 (+), Q9.2 (D)
SPI_DRV_NSCS: U3.29 (nSCS); also elsewhere on the board
SPI_MISO: R15.2, U3.26 (SDO); also elsewhere on the board
SPI_MOSI: U3.27 (SDI); also elsewhere on the board
SPI_SCK: U3.28 (SCLK); also elsewhere on the board
TIM1_CH1: U3.34 (INHA); also elsewhere on the board
TIM1_CH1N: U3.35 (INLA); also elsewhere on the board
TIM1_CH2: U3.36 (INHB); also elsewhere on the board
TIM1_CH2N: U3.37 (INLB); also elsewhere on the board
TIM1_CH3: U3.38 (INHC); also elsewhere on the board
TIM1_CH3N: U3.39 (INLC); also elsewhere on the board
VBUS: C19.1, C21.1, C22.1, C25.1, C26.1, C27.1, C28.1, C29.1, C30.1, C31.1, C32.1, C33.1, C34.1, C35.1, C36.1, C37.1, C38.1, C39.1, C40.1, C41.1, C50.2, C52.2, C53.2, C54.2, D10.1 (K), D11.1 (K), J9.1 (1_1), J12.1 (1_1), Q1.5 (D), Q1.6 (D), Q1.7 (D), Q1.8 (D), Q1.9 (D), Q3.5 (D), Q3.6 (D), Q3.7 (D), Q3.8 (D), Q3.9 (D), Q5.5 (D), Q5.6 (D), Q5.7 (D), Q5.8 (D), Q5.9 (D), Q9.3 (S), R12.2, R55.2, R59.2, R62.1, R64.1, R66.1, U3.4 (VM), U3.5 (VDRAIN), U7.3 (VIN); also elsewhere on the board

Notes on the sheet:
*Specific Layout Rules
These caps are not going to be assembled, already have in stock
This mux selects between the 5V produced by the buck if Vbus is present, or the 5V over USB if it is connected. It puts priority on the onboard 5V produced by thebuck converter (if both are present)
Primary use case here is to measure the voltage rails, not provide power.If needed, resistors can be changed to 0 ohm
INPUT POWER
DC-DC CONVERTERS + 5V MUX
EXPOSED POWER RAILS
Place 1uF near high side fets
Values for Snubber will be experimentally determined before population
INVERTER
Current Sense Discussion For this esc setup, the motor driver ensures that VREF/2 is the middle reference point for the current sensing, where here VREF is 3V3. From here, a gain of 10 is selected, in order to provide the mcu with an idle voltage of 1.65V when there is no current flowing through a 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
This capacitor bank is expected to handle a total ripple current of: i_c = 0.65 * I_phase_rms * 1.1 = 0.65 * 15.56 *1.1 = 11.12A The total amount of capacitance required for full load would be: C = i_c /(delta_V * f_sw). Given 10% max allowable voltage ripple on the DC Bus, capacitance required is: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
STATUS LEDS
18V UVLO Prot (thresh 0.958)
5V MUX
Bus bar pad for higher currents
Phase Pads
Input Filter
Using an Ideal Diode Controller was initially used, but replaced with a PMOS after considering regenerative affects from the motor, causing the controller to potentially shut off power
5V - 3V3
Reverse Polarity Protection
https://webench.ti.com/appinfo/webench/scripts/SDP.cgi?ID=DCC915FA82E52C05
24V-5V Buck

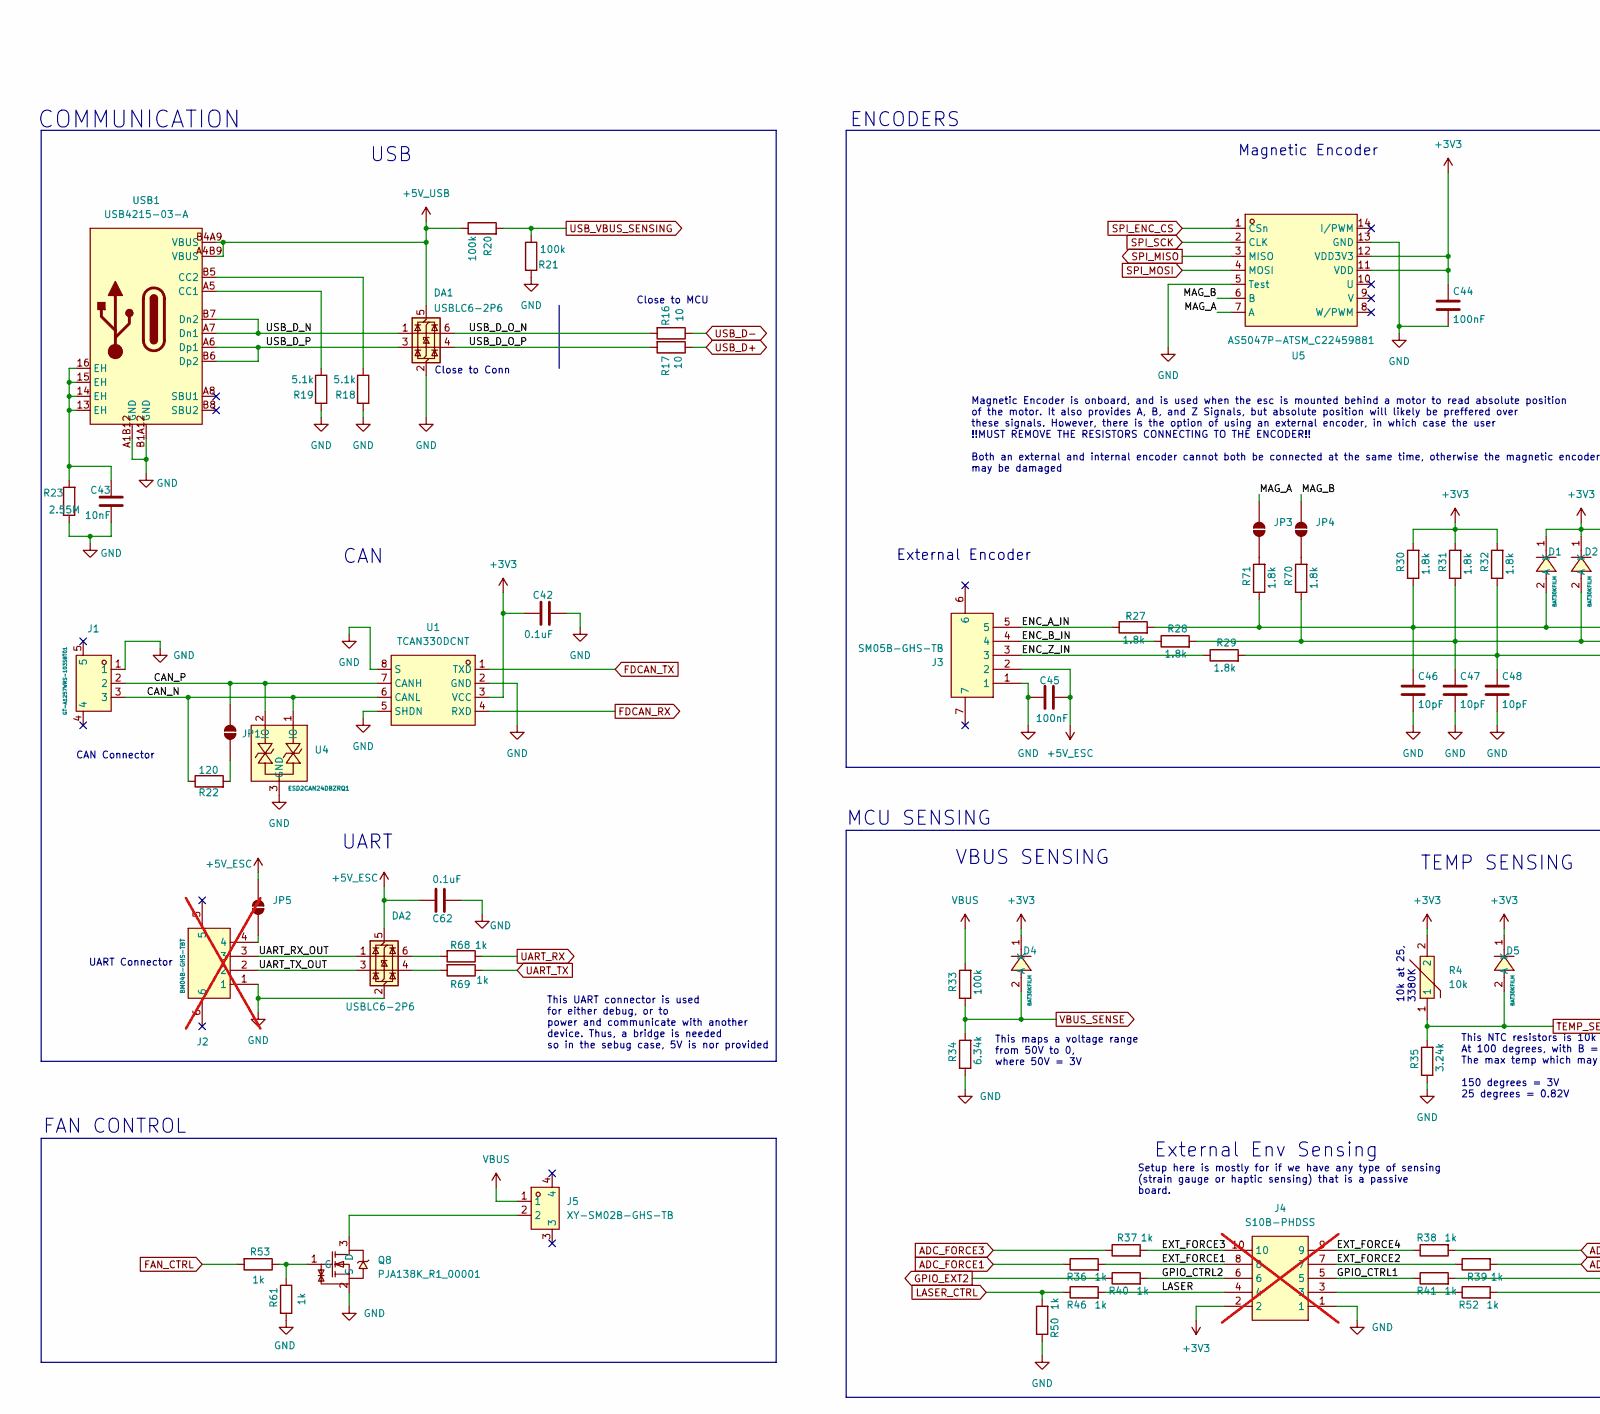
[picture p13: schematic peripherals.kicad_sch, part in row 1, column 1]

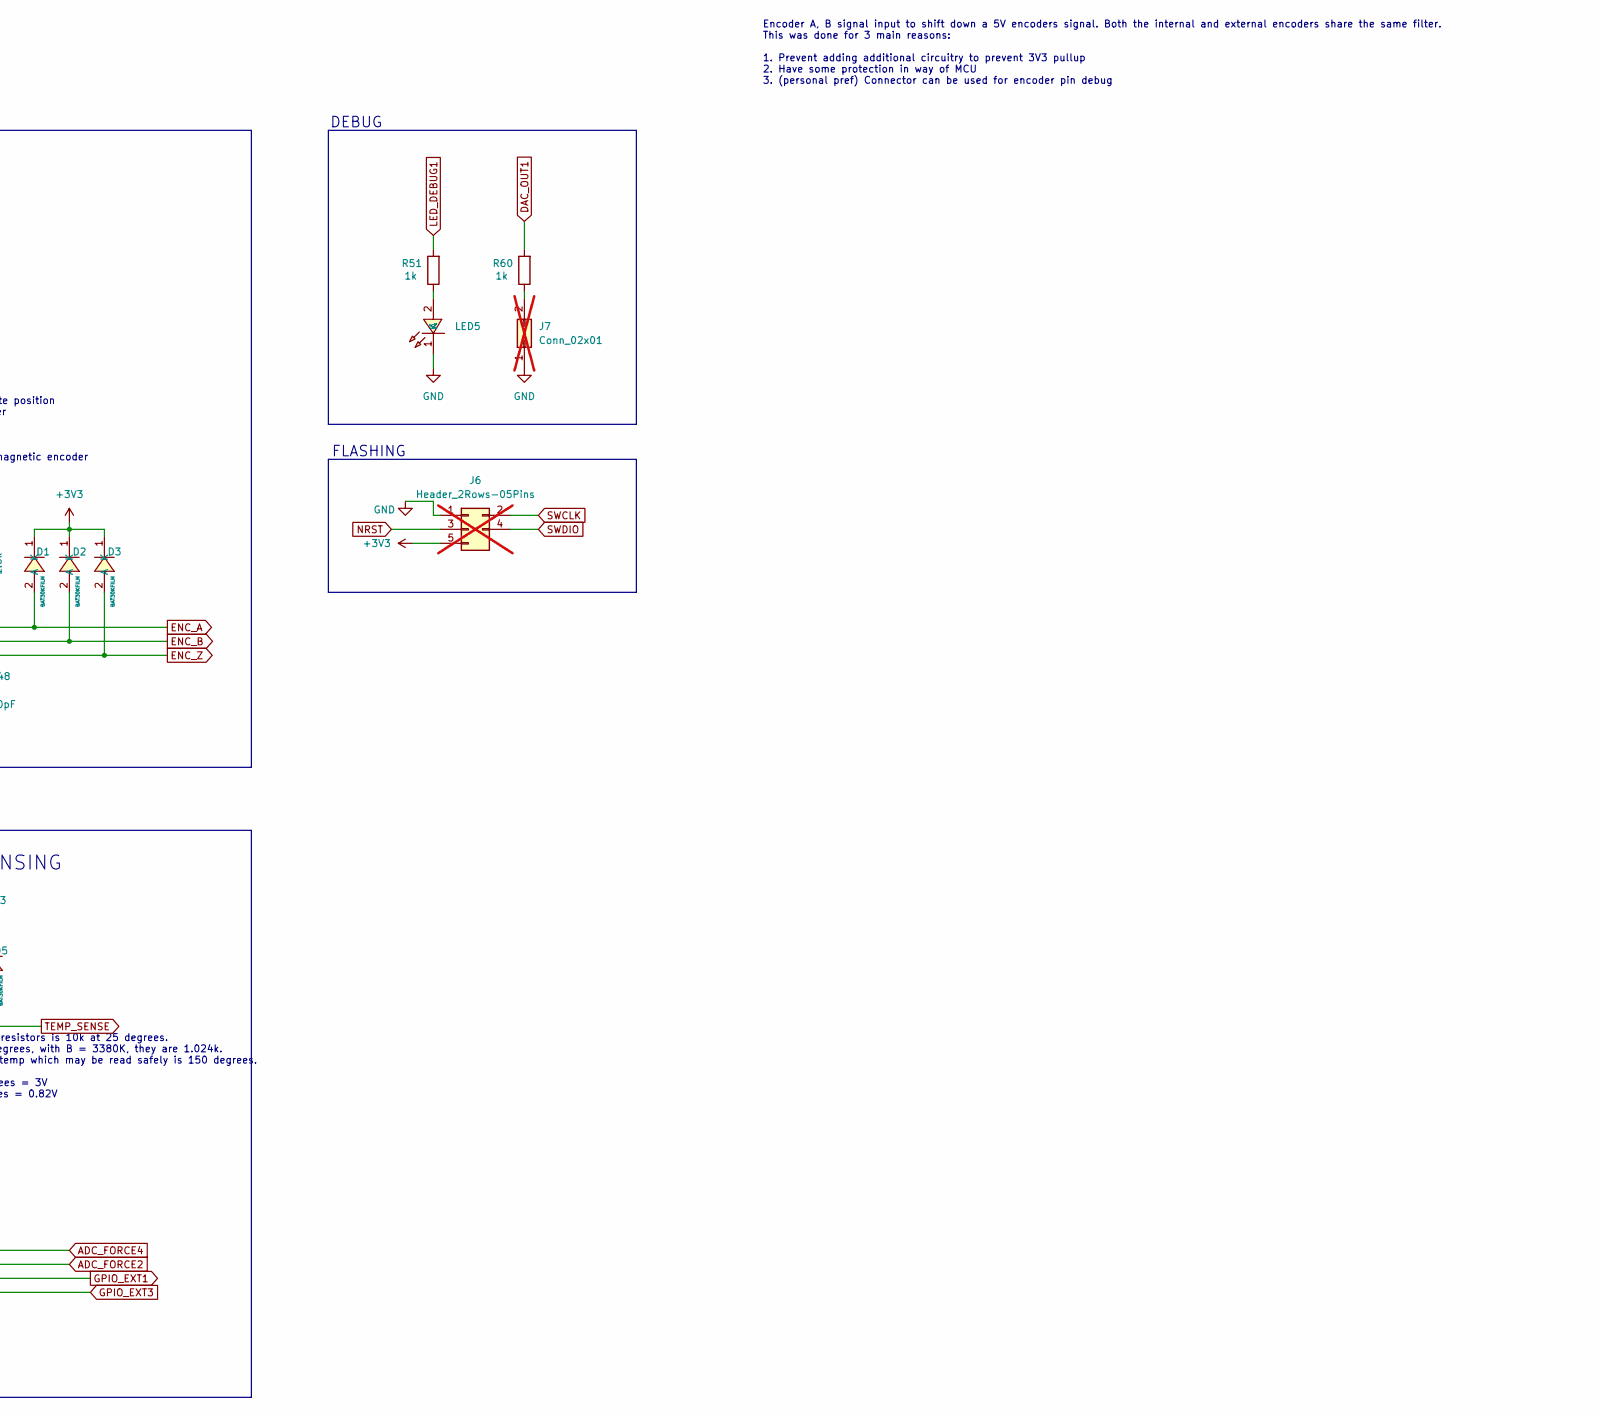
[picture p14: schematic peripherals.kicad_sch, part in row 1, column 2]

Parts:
C42, C62: 0.1uF; C_0603; LCSC Part C108079
C43: 10nF; C_0603; LCSC Part C519406
C44, C45: 100nF; C_0603; LCSC Part C108079
C46, C47, C48: 10pF; C_0603; LCSC Part C2168592
D1, D2, D3, D4, D5: BAT30KFILM; SOD-523_L1.2-W0.8-LS1.6-RD-1; MPN BAT30KFILM; LCSC Part C2926449
DA1, DA2: USBLC6-2P6; SOT-666-6_L1.6-W1.2-P0.50-LS1.6-BR; MPN USBLC6-2P6; LCSC Part C15999
J1: GT-A1257WRS-103SBT01; CONN-SMD_GT-A1257WRS-103SBT01; MPN GT-A1257WRS-103SBT01; LCSC Part C22472755
J2: BM04B-GHS-TBT; CONN-SMD_4P-P1.25_BM04B-GHS-TBT-LF-SN; MPN BM04B-GHS-TBT(LF)(SN); LCSC Part C161692; not fitted
J3: SM05B-GHS-TB; CONN-SMD_5P-P1.25_SM05B-GHS-TB-LF-SN; MPN SM05B-GHS-TB(LF)(SN); LCSC Part C189896
J4: S10B-PHDSS; CONN-TH_S10B-PHDSS-LF-SN; MPN S10B-PHDSS(LF)(SN); LCSC Part C161672; not fitted
J5: XY-SM02B-GHS-TB; CONN-SMD_SM02B-GHS-TB-LF-SN; MPN XY-SM02B-GHS-TB; LCSC Part C54582897
J6: Header_2Rows-05Pins; PinHeader_2_row_5_pin_P2.54mm_Vertical; not fitted
J7: Conn_02x01; PinHeader_1x02_P2.54mm_Vertical; not fitted
JP1, JP3, JP4, JP5: SolderJumper_2_Open; SolderJumper-2_P1.3mm_Open_TrianglePad1.0x1.5mm
LED5: LTST-C171KGKT; LED0805-RD; MPN LTST-C171KGKT; LCSC Part C98224
Q8: PJA138K_R1_00001; SOT-23_L2.9-W1.3-P1.90-LS2.4-BR; MPN PJA138K_R1_00001; LCSC Part C2902548
R4: 10k; R0603; MPN ERTJ1VG103FA; LCSC Part C153011
R16, R17: 10; R_0603; LCSC Part C844919
R18, R19: 5.1k; R_0603; LCSC Part C2907044
R20, R21, R33: 100k; R_0603; LCSC Part C2906980
R22: 120; R_0603; LCSC Part C2906988
R23: 2.55M; R_0603; LCSC Part C54102347
R27, R28, R29, R30, R31, R32, R70, R71: 1.8k; R_0603; LCSC Part C286575
R34: 6.34k; R_0603; LCSC Part C321969
R35: 3.24k; R_0603; LCSC Part C728589
R36, R37, R38, R39, R40, R41, R46, R50, R51, R52, R53, R60, R61, R68, R69: 1k; R_0603; LCSC Part C14676
U1: TCAN330DCNT; SOT-23-8_L2.9-W1.6-P0.65-LS2.8-BR; MPN TCAN330DCNT; LCSC Part C2671056
U4: ESD2CAN24DBZRQ1; SOT-23-3_L2.9-W1.3-P1.90-LS2.4-BR; MPN ESD2CAN24DBZRQ1; LCSC Part C5736151
U5: AS5047P-ATSM_C22459881; TSSOP-14_L5.0-W4.4-P0.65-LS6.4-BL; MPN AS5047P-ATSM; LCSC Part C22459881
USB1: USB4215-03-A; USB-C-SMD_GT-USB-7010B; MPN USB4215-03-A; LCSC Part C37616412

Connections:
+3V3: C42.1, C44.1, D1.1 (K), D2.1 (K), D3.1 (K), D4.1 (K), D5.1 (K), J4.2, J6.5, R4.2, R30.2, R31.2, R32.2, U1.3 (VCC), U5.11 (VDD), U5.12 (VDD3V3); also elsewhere on the board
+5V_ESC: C45.2, C62.2, DA2.5 (VBUS), J3.2, JP5.2 (B); also elsewhere on the board
+5V_USB: DA1.5 (VBUS), R20.1, USB1.A4B9 (VBUS), USB1.B4A9 (VBUS); also elsewhere on the board
/peripherals/CAN_N: J1.3, R22.1, U1.6 (CANL), U4.1 (IO)
/peripherals/CAN_P: J1.2, JP1.2 (B), U1.7 (CANH), U4.2 (IO)
/peripherals/ENC_A_IN: J3.5, R27.1
/peripherals/ENC_B_IN: J3.4, R28.1
/peripherals/ENC_Z_IN: J3.3, R29.1
/peripherals/EXT_FORCE1: J4.8, R36.2
/peripherals/EXT_FORCE2: J4.7, R39.1
/peripherals/EXT_FORCE3: J4.10, R37.2
/peripherals/EXT_FORCE4: J4.9, R38.1
/peripherals/GPIO_CTRL1: J4.5, R41.1
/peripherals/GPIO_CTRL2: J4.6, R40.2
/peripherals/LASER: J4.4, R46.2
/peripherals/MAG_A: JP3.2 (B), U5.7 (A)
/peripherals/MAG_B: JP4.2 (B), U5.6 (B)
/peripherals/UART_RX_OUT: DA2.1 (I/O1), J2.3
/peripherals/UART_TX_OUT: DA2.3 (I/O2), J2.2
/peripherals/USB_D_N: DA1.1 (I/O1), USB1.A7 (Dn1), USB1.B7 (Dn2)
/peripherals/USB_D_O_N: DA1.6 (I/O1), R16.2
/peripherals/USB_D_O_P: DA1.4 (I/O2), R17.2
/peripherals/USB_D_P: DA1.3 (I/O2), USB1.A6 (Dp1), USB1.B6 (Dp2)
ADC_FORCE1: R36.1; also elsewhere on the board
ADC_FORCE2: R39.2; also elsewhere on the board
ADC_FORCE3: R37.1; also elsewhere on the board
ADC_FORCE4: R38.2; also elsewhere on the board
DAC_OUT1: R60.2; also elsewhere on the board
ENC_A: C46.1, D1.2 (A), R27.2, R30.1, R71.1; also elsewhere on the board
ENC_B: C47.1, D2.2 (A), R28.2, R31.1, R70.1; also elsewhere on the board
ENC_Z: C48.1, D3.2 (A), R29.2, R32.1; also elsewhere on the board
FAN_CTRL: R53.2; also elsewhere on the board
FDCAN_RX: U1.4 (RXD); also elsewhere on the board
FDCAN_TX: U1.1 (TXD); also elsewhere on the board
GND: C42.2, C43.1, C44.2, C45.1, C46.2, C47.2, C48.2, C62.1, DA1.2 (GND), DA2.2 (GND), J1.1, J2.1, J3.1, J4.1, J6.1, J7.1, LED5.1 (K), Q8.2 (S), R18.2, R19.2, R21.2, R23.1, R34.1, R35.1, R50.1, R61.2, U1.2 (GND), U1.5 (SHDN), U1.8 (S), U4.3 (GND), U5.5 (Test), U5.13 (GND), USB1.A1B12 (GND), USB1.B1A12 (GND); also elsewhere on the board
GPIO_EXT1: R41.2; also elsewhere on the board
GPIO_EXT2: R40.1; also elsewhere on the board
GPIO_EXT3: R52.2; also elsewhere on the board
LASER_CTRL: R46.1, R50.2; also elsewhere on the board
LED_DEBUG1: R51.2; also elsewhere on the board
NRST: J6.3; also elsewhere on the board
unnamed: C43.2, R23.2, USB1.13 (EH), USB1.14 (EH), USB1.15 (EH), USB1.16 (EH)
unnamed: DA2.6 (I/O1), R68.2
unnamed: DA2.4 (I/O2), R69.2
unnamed: J4.3, R52.1
unnamed: J7.2, R60.1
unnamed: JP1.1 (A), R22.2
unnamed: JP3.1 (A), R71.2
unnamed: JP4.1 (A), R70.2
unnamed: J2.4, JP5.1 (A)
unnamed: LED5.2 (A), R51.1
unnamed: J5.2, Q8.3 (D)
unnamed: Q8.1 (G), R53.1, R61.1
unnamed: R19.1, USB1.A5 (CC1)
unnamed: R18.1, USB1.B5 (CC2)
SPI_ENC_CS: U5.1 (CSn); also elsewhere on the board
SPI_MISO: U5.3 (MISO); also elsewhere on the board
SPI_MOSI: U5.4 (MOSI); also elsewhere on the board
SPI_SCK: U5.2 (CLK); also elsewhere on the board
SWCLK: J6.2; also elsewhere on the board
SWDIO: J6.4; also elsewhere on the board
TEMP_SENSE: D5.2 (A), R4.1, R35.2; also elsewhere on the board
UART_RX: R68.1; also elsewhere on the board
UART_TX: R69.1; also elsewhere on the board
USB_D+: R17.1; also elsewhere on the board
USB_D-: R16.1; also elsewhere on the board
USB_VBUS_SENSING: R20.2, R21.1; also elsewhere on the board
VBUS: J5.1, R33.2; also elsewhere on the board
VBUS_SENSE: D4.2 (A), R33.1, R34.2; also elsewhere on the board

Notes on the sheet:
External Encoder
This NTC resistors is 10k at 25 degrees. At 100 degrees, with B = 3380K, they are 1.024k. The max temp which may be read safely is 150 degrees. 150 degrees = 3V 25 degrees = 0.82V
This maps a voltage range from 50V to 0, where 50V = 3V
Magnetic Encoder
UART
This UART connector is used for either debug, or to power and communicate with another device. Thus, a bridge is needed so in the sebug case, 5V is nor provided
FLASHING
Close to Conn
ENCODERS
COMMUNICATION
TEMP SENSING
FAN CONTROL
Encoder A, B signal input to shift down a 5V encoders signal. Both the internal and external encoders share the same filter. This was done for 3 main reasons: 1. Prevent adding additional circuitry to prevent 3V3 pullup 2. Have some protection in way of MCU 3. (personal pref) Connector can be used 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
External Env Sensing
Setup here is mostly for if we have any type of sensing (strain gauge or haptic sensing) that is a passive board.
MCU SENSING
USB
Magnetic Encoder is onboard, and is used when the esc is mounted behind a motor to read absolute position of the motor. It also provides A, B, and Z Signals, but absolute position will likely be preffered over these signals. However, there is the option of using an external encoder, in which case t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
10k at 25, 3380K
VBUS SENSING
DEBUG
UART Connector
Close to MCU
CAN
CAN Connector

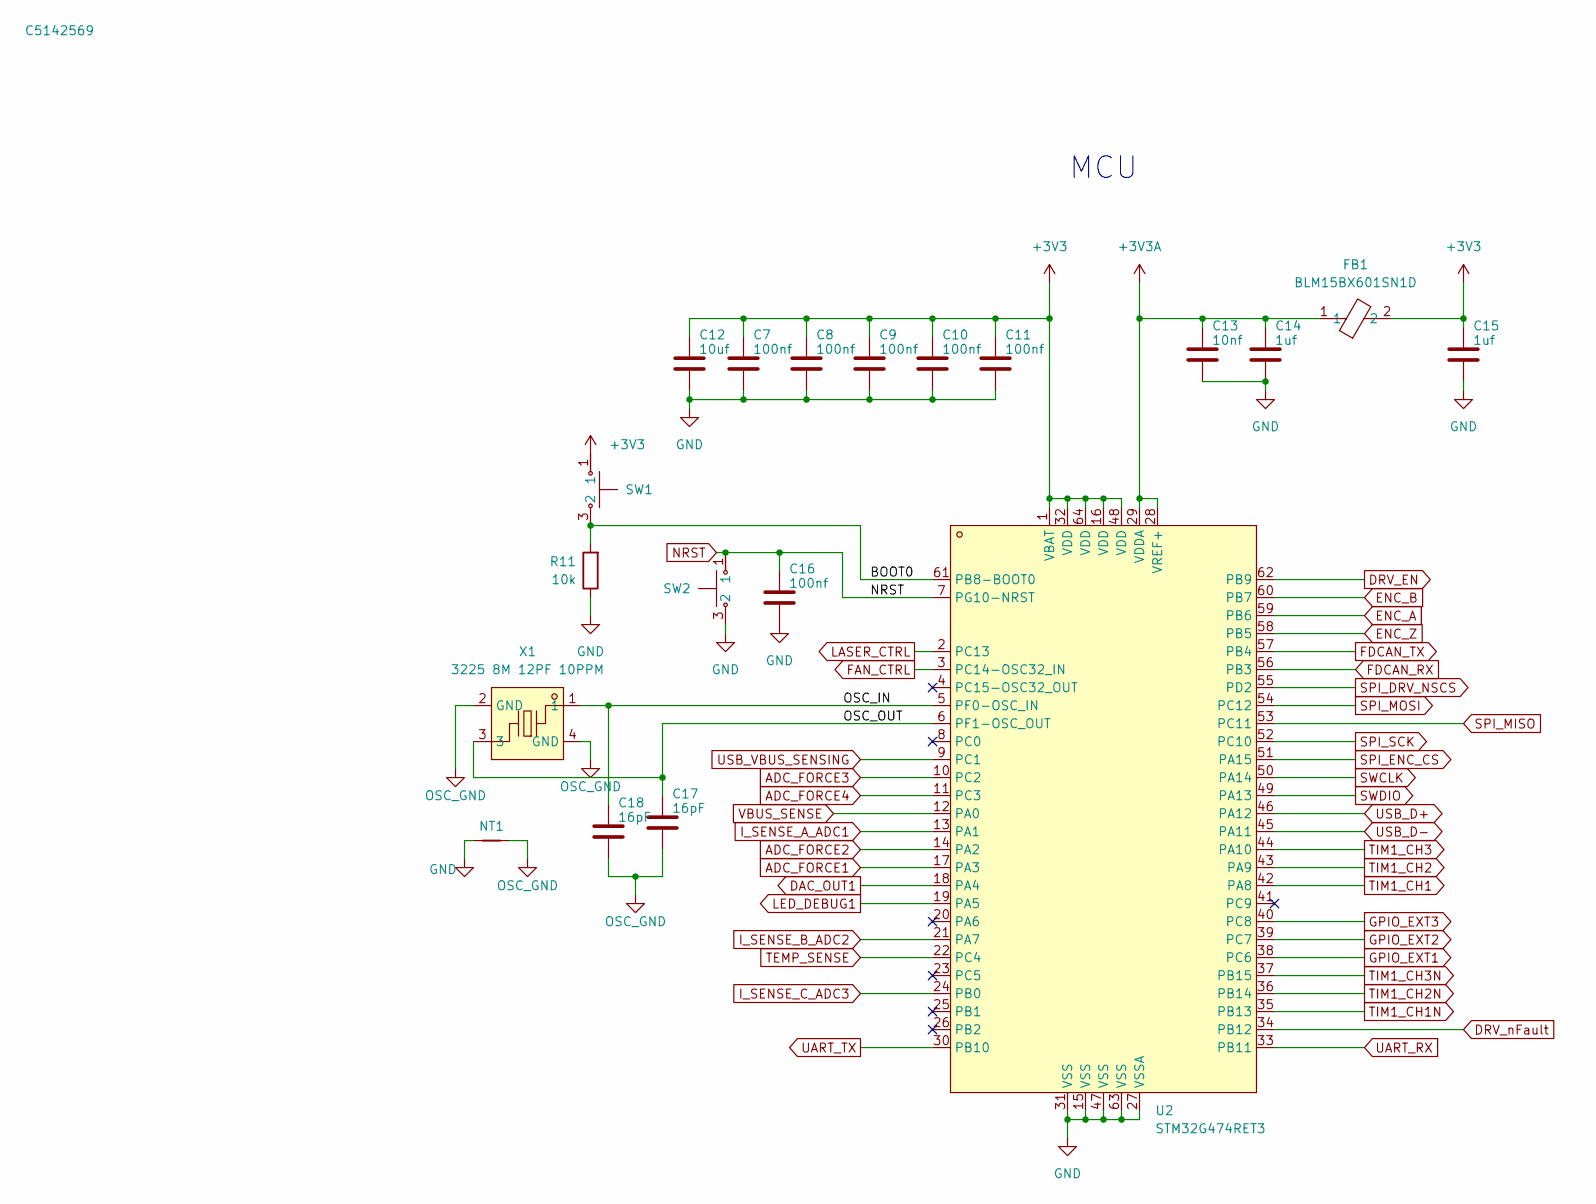
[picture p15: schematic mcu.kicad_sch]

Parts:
C7, C8, C9, C10, C11, C16: 100nf; C_0603; LCSC Part C108079
C12: 10uf; C_0805; LCSC Part C711098
C13: 10nf; C_0603; LCSC Part C519406
C14, C15: 1uf; C_0603; LCSC Part C106248
C17, C18: 16pF; C_0402_1005Metric; LCSC Part C5142569
FB1: BLM15BX601SN1D; L0402; MPN BLM15BX601SN1D; LCSC Part C710336
NT1: NetTie_2; NetTie-2_SMD_Pad0.5mm
R11: 10k; R_0603; LCSC Part C98220
SW1, SW2: SH-1808SN-250GF; SW-SMD_4P-L4.2-W3.4-P2.15-LS5.2; MPN SH-1808SN-250gf; LCSC Part C52092028
U2: STM32G474RET3; LQFP-64_L10.0-W10.0-P0.50-LS12.0-BL; MPN STM32G474RET3; LCSC Part C1236669
X1: 3225 8M 12PF 10PPM; CRYSTAL-SMD_4P-L3.2-W2.5-BL; MPN 3225 8M 12PF 10PPM; LCSC Part C5181478

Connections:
+3V3: C7.1, C8.1, C9.1, C10.1, C11.1, C12.1, C15.1, FB1.2, SW1.1, SW1.2, U2.1 (VBAT), U2.16 (VDD), U2.32 (VDD), U2.48 (VDD), U2.64 (VDD); also elsewhere on the board
+3V3A: C13.1, C14.1, FB1.1, U2.28 (VREF+), U2.29 (VDDA)
/mcu/BOOT0: R11.2, SW1.3 (2), SW1.4, U2.61 (PB8-BOOT0)
/mcu/OSC_IN: C18.1, U2.5 (PF0-OSC_IN), X1.1
/mcu/OSC_OUT: C17.1, U2.6 (PF1-OSC_OUT), X1.3
ADC_FORCE1: U2.17 (PA3); also elsewhere on the board
ADC_FORCE2: U2.14 (PA2); also elsewhere on the board
ADC_FORCE3: U2.10 (PC2); also elsewhere on the board
ADC_FORCE4: U2.11 (PC3); also elsewhere on the board
DAC_OUT1: U2.18 (PA4); also elsewhere on the board
DRV_EN: U2.62 (PB9); also elsewhere on the board
DRV_nFault: U2.34 (PB12); also elsewhere on the board
ENC_A: U2.59 (PB6); also elsewhere on the board
ENC_B: U2.60 (PB7); also elsewhere on the board
ENC_Z: U2.58 (PB5); also elsewhere on the board
FAN_CTRL: U2.3 (PC14-OSC32_IN); also elsewhere on the board
FDCAN_RX: U2.56 (PB3); also elsewhere on the board
FDCAN_TX: U2.57 (PB4); also elsewhere on the board
GND: C7.2, C8.2, C9.2, C10.2, C11.2, C12.2, C13.2, C14.2, C15.2, C16.2, NT1.1, R11.1, SW2.3 (2), SW2.4, U2.15 (VSS), U2.27 (VSSA), U2.31 (VSS), U2.47 (VSS), U2.63 (VSS); also elsewhere on the board
GPIO_EXT1: U2.38 (PC6); also elsewhere on the board
GPIO_EXT2: U2.39 (PC7); also elsewhere on the board
GPIO_EXT3: U2.40 (PC8); also elsewhere on the board
I_SENSE_A_ADC1: U2.13 (PA1); also elsewhere on the board
I_SENSE_B_ADC2: U2.21 (PA7); also elsewhere on the board
I_SENSE_C_ADC3: U2.24 (PB0); also elsewhere on the board
LASER_CTRL: U2.2 (PC13); also elsewhere on the board
LED_DEBUG1: U2.19 (PA5); also elsewhere on the board
NRST: C16.1, SW2.1, SW2.2, U2.7 (PG10-NRST); also elsewhere on the board
OSC_GND: C17.2, C18.2, NT1.2, X1.2 (GND), X1.4 (GND)
SPI_DRV_NSCS: U2.55 (PD2); also elsewhere on the board
SPI_ENC_CS: U2.51 (PA15); also elsewhere on the board
SPI_MISO: U2.53 (PC11); also elsewhere on the board
SPI_MOSI: U2.54 (PC12); also elsewhere on the board
SPI_SCK: U2.52 (PC10); also elsewhere on the board
SWCLK: U2.50 (PA14); also elsewhere on the board
SWDIO: U2.49 (PA13); also elsewhere on the board
TEMP_SENSE: U2.22 (PC4); also elsewhere on the board
TIM1_CH1: U2.42 (PA8); also elsewhere on the board
TIM1_CH1N: U2.35 (PB13); also elsewhere on the board
TIM1_CH2: U2.43 (PA9); also elsewhere on the board
TIM1_CH2N: U2.36 (PB14); also elsewhere on the board
TIM1_CH3: U2.44 (PA10); also elsewhere on the board
TIM1_CH3N: U2.37 (PB15); also elsewhere on the board
UART_RX: U2.33 (PB11); also elsewhere on the board
UART_TX: U2.30 (PB10); also elsewhere on the board
USB_D+: U2.46 (PA12); also elsewhere on the board
USB_D-: U2.45 (PA11); also elsewhere on the board
USB_VBUS_SENSING: U2.9 (PC1); also elsewhere on the board
VBUS_SENSE: U2.12 (PA0); also elsewhere on the board

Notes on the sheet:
MCU

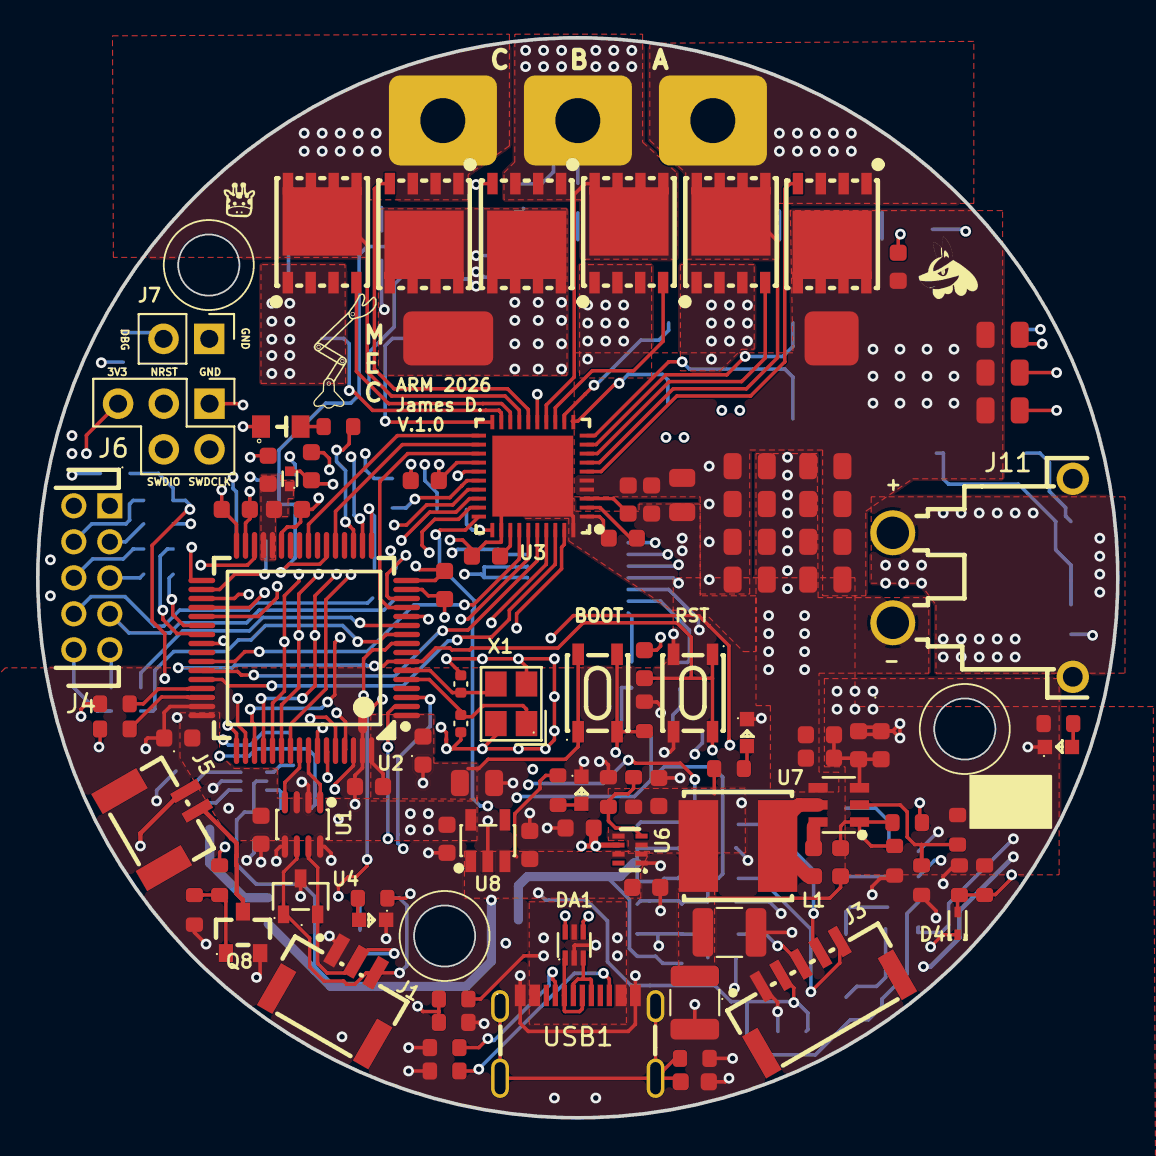
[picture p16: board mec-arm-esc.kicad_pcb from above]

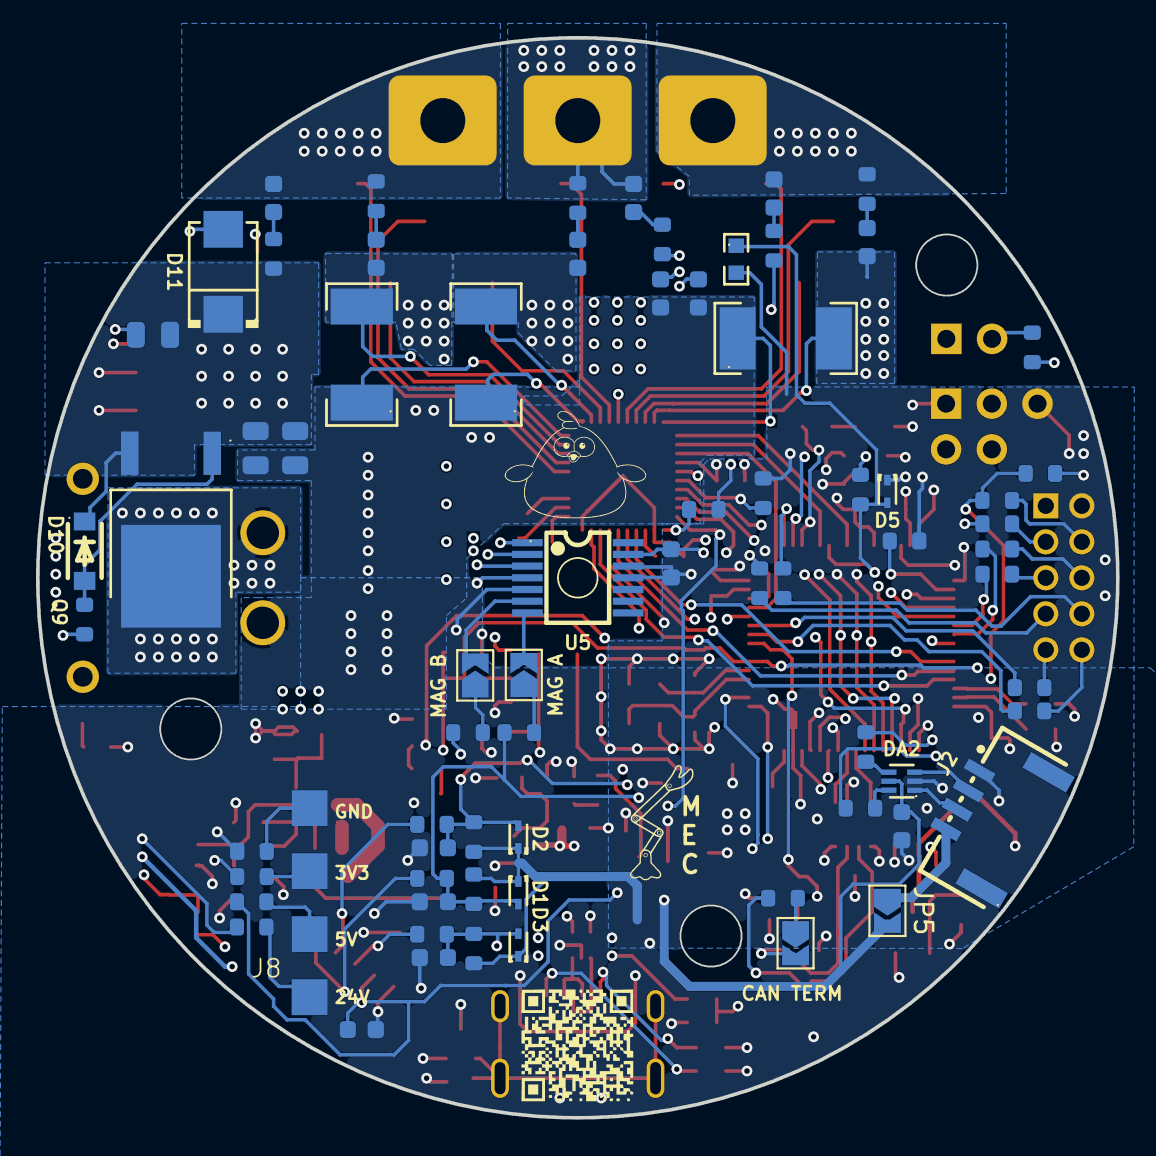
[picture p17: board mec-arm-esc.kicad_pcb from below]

Board: 4 copper layers, 60.0 x 60.0 mm, 178 parts (72 on the bottom side), 125 nets.

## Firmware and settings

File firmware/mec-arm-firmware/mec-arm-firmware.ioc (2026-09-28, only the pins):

Mcu.UserName=STM32G474RETx
PA0.Signal=ADC2_IN1
PA1.Signal=SharedAnalog_PA1
PA10.Signal=S_TIM1_CH3
PA11.Signal=USB_DM
PA12.Signal=USB_DP
PA13.Signal=SYS_JTMS-SWDIO
PA14.Signal=SYS_JTCK-SWCLK
PA15.GPIO_Label=ENC_CS
PA15.Signal=GPIO_Output
PA2.Signal=ADC1_IN3
PA3.Signal=ADC1_IN4
PA4.Signal=COMP_DAC11_group
PA5.GPIO_Label=LED_DEBUG2
PA5.Signal=GPIO_Output
PA7.Signal=SharedAnalog_PA7
PA8.Signal=S_TIM1_CH1
PA9.Signal=S_TIM1_CH2
PB0.Signal=SharedAnalog_PB0
PB10.Signal=USART3_TX
PB11.Signal=USART3_RX
PB12.Signal=TIM1_BKIN
PB13.Signal=TIM1_CH1N
PB14.Signal=TIM1_CH2N
PB15.Signal=TIM1_CH3N
PB3.Signal=FDCAN3_RX
PB4.Signal=FDCAN3_TX
PB5.GPIO_Label=ENC_Z
PB5.Signal=GPXTI5
PB6.Signal=S_TIM4_CH1
PB7.Signal=S_TIM4_CH2
PB9.GPIO_Label=DRV_ENABLE
PB9.Signal=GPIO_Output
PC0.GPIO_Label=LED_DEBUG1
PC0.Signal=GPIO_Output
PC1.GPIO_Label=USB_VBUS_SENSE
PC1.Signal=GPXTI1
PC10.Signal=SPI3_SCK
PC11.Signal=SPI3_MISO
PC12.Signal=SPI3_MOSI
PC13.GPIO_Label=LAZER_EN
PC13.Signal=GPIO_Output
PC14-OSC32_IN.GPIO_Label=FAN_EN
PC14-OSC32_IN.Signal=GPIO_Output
PC2.Signal=ADC1_IN8
PC3.Signal=ADC1_IN9
PC4.Signal=ADC2_IN5
PC6.GPIO_Label=GPIO_SPARE1
PC6.Signal=GPIO_Output
PC7.GPIO_Label=GPIO_SPARE2
PC7.Signal=GPIO_Output
PC8.GPIO_Label=GPIO_SPARE3
PC8.Signal=GPIO_Output
PD2.GPIO_Label=DRV_nSCS
PD2.Signal=GPIO_Output
PF0-OSC_IN.Signal=RCC_OSC_IN
PF1-OSC_OUT.Signal=RCC_OSC_OUT

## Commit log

2026-06-23 initial project creation
    [mec-arm-esc.kicad_pcb, mec-arm-esc.kicad_sch, powerstage.kicad_sch]
2026-06-23 first half bridge added
    [powerstage.kicad_sch]
2026-06-23 fixed mosfet symbol
    [powerstage.kicad_sch]
2026-06-24 finish single phase
    [powerstage.kicad_sch]
2026-06-25 added mcu sheet
    [mec-arm-esc.kicad_sch, powerstage.kicad_sch, untitled.kicad_sch]
2026-06-25 shunt phase a added
    [powerstage.kicad_sch]
2026-06-26 added MCU power and ground + altered symbol
    [powerstage.kicad_sch, untitled.kicad_sch]
2026-07-10 added renamed mcu
    [mcu.kicad_sch]
2026-08-20 Added V1 of stm32 pinout
2026-08-20 updated arm with proper basic mcu routing
    [.kicad_sch, mcuREF.kicad_sch]
2026-08-20 added backups
    [mec-arm-esc.kicad_sch, powerstage.kicad_sch]
2026-08-20 remove irrelevent files
    [mcuREF.kicad_sch]
2026-08-21 Finished Bare MCU + Oscillator, added prelim powerstage additions
    [.kicad_sch, mcu.kicad_sch, mec-arm-esc.kicad_sch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]
2026-08-25 Completed inverter, started calculation for input power
    [mcu.kicad_sch, mec-arm-esc.kicad_sch, powerstage.kicad_sch]
2026-09-02 Changed the components in all the drawings to reflect the new library, and added vbus sensing
    [mcu.kicad_sch, mec-arm-esc.kicad_sch, peripherals.kicad_sch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]
2026-09-04 Added peripheral systems, and corresponding mcu entries
    [mcu.kicad_sch, mec-arm-esc.kicad_pcb, peripherals.kicad_sch]
2026-09-07 Schematic Done, review 1
    [.kicad_sch, mcu.kicad_sch, mcuREF.kicad_sch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]
2026-09-15 Done placement, starting routing
    [mcu.kicad_sch, mcuREF.kicad_sch, mec-arm-esc.kicad_pcb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]
2026-09-20 All signal routing finishes, power and planes not yet
    [mcu.kicad_sch, mec-arm-esc.kicad_pcb, peripherals.kicad_sch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]
2026-09-25 Revise flowchart in README for project updates
    Updated the flowchart in the README to reflect changes in the project's structure and status.
2026-09-25 Refactor joint validation section in README
    Moved joint validation tasks outside of the subgraph for clarity.
2026-09-25 Stop tracking KiCad local history
2026-09-25 added multi-page MEC-arm website
2026-09-25 Use supplied MEC-Arm logo throughout website
2026-09-26 added landing page info
2026-09-28 updates website esc information
2026-09-28 updated landing page
2026-09-28 updated landing page images
2026-09-28 Completed ESC PCB
    [MEC_ARM_REV1_bom.csv, MEC_ARM_REV1_designators.csv, MEC_ARM_REV1_positions.csv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]
2026-09-28 added more circuit pictures
2026-09-28 Restructure ESC documentation and add Powerstage overview
2026-09-29 Improve ESC navigation and documentation formatting
2026-09-29 Mark Joint ESC as under test
2026-09-29 Add Joint ESC specifications
2026-10-22 Generated STM32 Code from ioc
2026-10-25 Working LED blinky with LED fixed ioc file
2026-10-25 Updated ioc with LED number fix
